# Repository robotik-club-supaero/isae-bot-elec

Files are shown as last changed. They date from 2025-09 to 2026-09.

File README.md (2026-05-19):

# Elec2025-26
elec 2025 2026 comme dans le titre en fait

# Pinout ESP32-Devkit

Ce guide fournit une référence exhaustive pour l'utilisation des broches du module **ESP32-DevKitC-32D**. Il récapitule les fonctions de chaque broche, classe les GPIO par niveau de sécurité, et liste les règles de conception essentielles pour éviter les comportements erratiques au démarrage (boot) ou le blocage du téléversement.
Lien vers un sheets qui est plutôt clair : https://docs.google.com/spreadsheets/d/1OCtBKPCofokwxsqIV4q3fY71EqnTtfXIetnAtifBfJc/edit?usp=sharing

---

## 🗺️ 1. Synthèse Globale du Pinout

> [!CAUTION]
> **DANGER CRITIQUE POUR LE MATÉRIEL :**
> **NE JAMAIS ENVOYER PLUS DE 3.3V A AUCUNE DES PINS GPIO de l'ESP32.** > Les broches ne sont pas tolérantes au 5V. Toute tension supérieure à 3.3V détruira instantanément la broche ou la puce entière. Utilisez un pont diviseur ou un Level Shifter pour les signaux autres.

### 🔌 Broches d'Alimentation et Contrôle Physique
Ces broches ne sont pas programmables. Elles gèrent l'infrastructure électrique et logique de la carte.

| Nom sur Schéma | Fonction Matérielle | Recommandations de Conception |
| :--- | :--- | :--- |
| **VIN** | Entrée d'alimentation principale (5V) | Liée au régulateur de tension interne. À utiliser pour alimenter la carte sans câble USB. |
| **3V3** | Sortie ou Entrée d'alimentation 3.3V | Sortie du régulateur interne ou entrée régulée. Ne jamais injecter plus de 3.3V sous peine de destruction. |
| **GND / GND1** | Masse de référence (0V) | Point commun pour tous les signaux et alimentations du système. |
| **EN** | Équivalent Hardware Reset | Maintenu à 3.3V en interne. Forcer à la masse (GND) éteint la puce. Une transition bas ➔ haut déclenche un Hard Reset. |

---

## 🚦 2. Classification des GPIO par Niveau de Sécurité

### 🟢 Liste Verte : 100% Sûres (Aucune restriction)
Ces broches sont entièrement bidirectionnelles, acceptent le mode `INPUT`, `OUTPUT`, les interruptions matérielles, ainsi que les résistances de tirage (*pull-up* / *pull-down*) internes. **À utiliser en priorité absolue.**

| Nom | N° GPIO | Fonctions Spécifiques / Alternatives |
| :--- | :--- | :--- |
| **IO13** | GPIO 13 | Entrée/Sortie standard |
| **IO14** | GPIO 14 | Sort du PWM au boot (Léger glitch possible à la mise sous tension) |
| **IO16** | GPIO 16 | Entrée/Sortie standard |
| **IO17** | GPIO 17 | Entrée/Sortie standard |
| **IO19** | GPIO 19 | Entrée/Sortie standard (Souvent utilisé pour SPI MISO) |
| **IO21** | GPIO 21 | Bus I2C Matériel : **SDA** (Par défaut) |
| **IO22** | GPIO 22 | Bus I2C Matériel : **SCL** (Par défaut) |
| **IO23** | GPIO 23 | Entrée/Sortie standard (Souvent utilisé pour SPI MOSI) |
| **IO25** | GPIO 25 | Intègre un DAC (Convertisseur Numérique-Analogique matériel) |
| **IO26** | GPIO 26 | Intègre un DAC (Convertisseur Numérique-Analogique matériel) |
| **IO27** | GPIO 27 | Entrée/Sortie standard |
| **IO32** | GPIO 32 | Entrée/Sortie standard |
| **IO33** | GPIO 33 | Entrée/Sortie standard |

### 🟡 Liste Orange : Entrées Uniquement (*Input Only*)
Ces broches sont uniquement capables de lire un signal électrique. La commande `pinMode(X, OUTPUT)` n'a aucun effet physique dessus.

| Nom | N° GPIO | Caractéristiques Critiques |
| :--- | :--- | :--- |
| **IO34** | GPIO 34 | **Pas de pull-up/pull-down interne**. État flottant sans résistance externe. |
| **IO35** | GPIO 35 | **Pas de pull-up/pull-down interne**. État flottant sans résistance externe. |
| **VP** | GPIO 36 | Sensor VP. **Pas de pull-up/pull-down interne**. Entrée idéal analogique. |
| **VN** | GPIO 39 | Sensor VN. **Pas de pull-up/pull-down interne**. Entrée idéal analogique. |

> 💡 **Le Super-Pouvoir de l'ADC1 :** Contrairement aux broches de l'ADC2, les entrées analogiques de l'ADC1 (**GPIO 34, 35, 36, 39**) restent parfaitement fonctionnelles et stables lorsque le module Wi-Fi de l'ESP32 est actif. Utilisez-les en priorité pour vos capteurs critiques (potentiomètres, mesures analogiques, joysticks).

### 🔴 Liste Rouge : Les Strapping Pins (Risque de blocage au boot)
Ces broches agissent comme des configurateurs matériels au moment précis de l'allumage. **Règle d'or : Ne jamais les câbler comme entrées reliées à des commutateurs ou capteurs actifs au démarrage.** Si nécessaire, utilisez-les préférentiellement en **Sortie (Output)** pour des composants non critiques.

| Nom | N° GPIO | Rôle au Démarrage / Comportement Attendu | Risque en cas d'erreur matérielle |
| :--- | :--- | :--- | :--- |
| **IO0** | GPIO 0 | **Boot Mode Select**. Haut = Exécution Normale. Bas = Mode Flashage/Téléchargement. | Bloque le téléversement ou empêche le code utilisateur de s'exécuter de manière autonome. |
| **IO2** | GPIO 2 | Doit être maintenu à l'état **BAS** (ou flottant) pour entrer en mode Flash. | Conjointement au GPIO 0, si forcé à l'état haut au boot, le flashage échoue. |
| **IO5** | GPIO 5 | Configure le timing du mode esclave SDIO. | Peut empêcher le processeur d'initialiser correctement certains bus. |
| **IO12** | GPIO 12 | **Tension Flash (VDD_SDIO)**. Haut = 1.8V. Bas = 3.3V (Nécessaire pour le module WROOM). | **Boot fails if high** : Si tiré vers le haut par un composant au démarrage, la mémoire flash manque de tension ➔ crash immédiat. |
| **IO15** | GPIO 15 | Contrôle l'émission des logs de debug de démarrage sur UART0. | Émet des micro-impulsions au boot (peut faire brièvement clignoter une LED ou commuter un transistor). |

### ❌ Liste Noire : Interdiction Absolue (Mémoire Interne SPI)
**Ne tentez jamais de les déclarer ou de les manipuler dans votre code.**
* **GPIO 1 (TX0) & GPIO 3 (RX0) :** Réservées au convertisseur USB-Série de la carte de développement. Les utiliser bloque le téléversement du code et casse la communication avec le Moniteur Série.

### Liste a éviter : Pins high au boot
Ces broches sont high (à 3.3V) pendant le boot & le setup. Connectez un composant (un moteur par exemple) dessus le fera démarrer à chaque upload du code. C'est chiant, on évite si c'est un composant qui reçoit du courant et qui produit une action. Un interrupteur, une led c'est ok par exemple
* [1 | 3 | 5 | 14 | 15] **GPIO 1 (TX0) & GPIO 3 (RX0) & GPIO 5 & GPIO 14 & GPIO 15 :** Sont high au boot & envoie des signaux pwm ou high

<p align="center">
  Pinout ESP32 DOIT DevKit V1
</p>

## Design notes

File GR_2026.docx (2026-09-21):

Gros Robot Architecture

Carte Alimentation
Carte Raspberry Hat
Carte Propulsion
Carte Action
Carte Constructeur

INTRODUCTION

Le gros robot (« GR ») est le robot principal du club. Il accompli les tâches les plus complexes et rapporte donc le plus de point.

Pour cela, il possède 5 cartes électroniques nécessaire à son bon fonctionnement :

- Carte Alimentation
- Carte Propulsion
- Carte Action
- Carte Raspberry Pi Hat
- Carte Constructeur

On va ici détailler les fonctions de chacune d’elle ainsi que leurs interconnexions.

DESCRIPTION GENERALE

Chaque carte possède sa propre fonction qui permet au robot de fonctionner :

- Carte Alimentation : Alimente les autres cartes du robot à partir de batteries mais aussi le lidar.
- Carte Propulsion : Gère les déplacements du robot (moteurs + odomètres) en connexion avec la carte constructeur.
- Carte Action : Gère tous les actionneurs et capteurs du robot. Refaite chaque année en fonction des règles.
- Carte Raspberry Pi Hat : Interface avec le Raspberry Pi. (Faire coucou à l’info pour plus de détails) .
- Carte Constructeur : Carte du constructeur des moteurs/odomètres. Seule carte professionnelle. Ne sera pas détaillée.

INTERCONNEXIONS

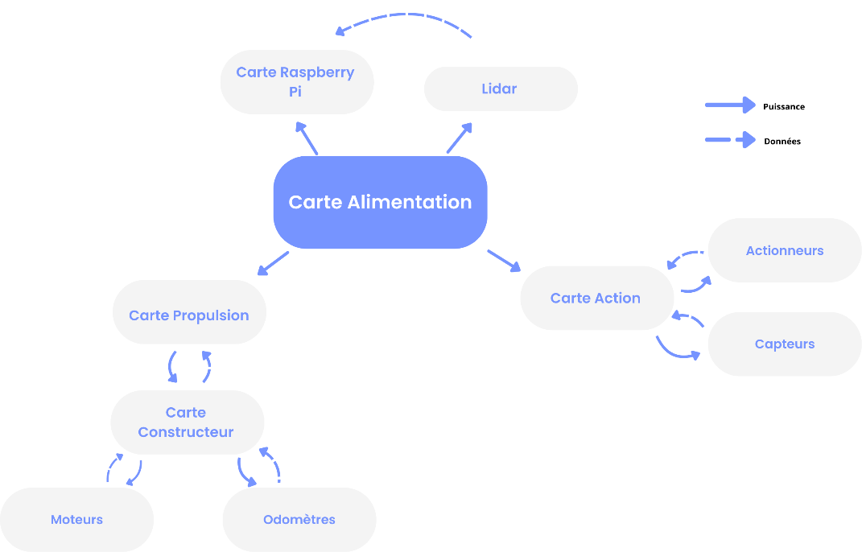
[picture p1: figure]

Les cartes ne sont pas indépendantes comme sur le schéma, elles communiquent entre elles avec ROS mais ça c’est le domaine de l’info :)

De plus, on divise tous les composants en deux catégories : La puissance et la logique.

- La puissance concerne les actionneurs comme les moteurs, les servos, les pompes, etc
- La logique concerne les capteurs, les microcontrôleurs, les odomètres, etc

CARTE ALIMENTATION

L’alimentation est le point central du robot, sans elle, rien ne marche. Elle permet :

- De générer les tensions d’alimentation nécessaire sur les autres cartes à partir de batteries de 24V.
- D’alimenter la carte Action en 5V, 12V, et 15V.
- D’alimenter la carte Propulsion en 24V.
- D’alimenter la carte Raspberry Pi en 5V.
- D’alimenter le Lidar en 5V ou 15V selon le modèle.
- Gérer le bouton d’arrêt d’urgence (BAU) et le l’interrupteur ON/OFF.

PS : Toutes les tensions de puissance seront notées _P et celles de logiques _L.

On peut la décomposer en 5 grandes parties :

- La batterie ainsi que le BAU et le ON/OFF contrôlés grâce à des relais. De plus, elle décompose la tension en deux : Une tension de puissance pour les actionneurs/capteurs (Vin_P) et une tension pour la logique (Vin_L).
- La conversion des tensions logiques. Les TSR1 génèrent du 5V à 1A maximum, et le TEN 30 génère du 5V à 6A maximum.
- Une 3ème gère la conversion des tensions de puissance. La TSR1 qui génère du 5V à 1A maximum, les TSR2 qui génèrent du 12V à 2A maximum.
- La redistribution vers les autres cartes à l’aide de connecteurs molex.
- Les leds témoins de chaque tension présente sur la carte.

La base a été faite en 2021 et modifiée cette année, en 2026, pour changer le convertisseur de tension du Raspberry car le nouveau model fonctionne en 5A.

SCHÉMA ÉLECTRIQUE

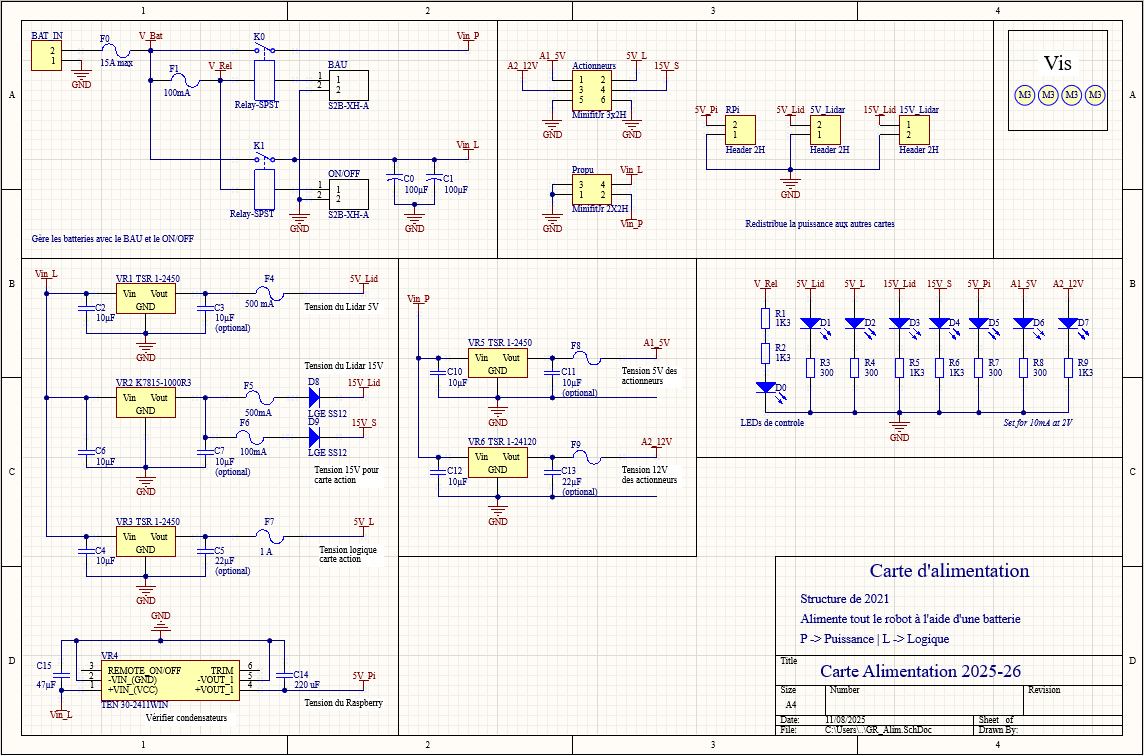
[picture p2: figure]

Et la carte de 2026:

- VR1: 5V-1A – TSR 1-2450
- VR2: 15V-1A – K7815-1000R3
- VR3: 5V-1A – TSR 1-2450
- VR4: 5V-6A – TEN 30-2411WIN
- VR5: 5V-1A – TSR 1-2450
- VR6: 12V-1A – TSR 1-24120
- VR6: 12V-2A – TSR 2-24120

Les convertisseurs réellement soudés sur la carte de 2021:

- VR2: K7815-1000R3 (15V–1A)
- VR3: TSR 1-2450 (5V-1A)
- VR4: TSR 1-2450 (5V–1A)
- VR5: THN 15-2411WIR (5V–3A)
- VR6: K7805-2000R3 (5V-2A)
- VR7: K7812-1000R3 (12V-1A)

COMPOSANTS

Les composants utilisés pour réaliser cette carte sont les suivants :

Composant | Valeur / Référence | Identificateur | Quantité
Relay SPST | / | K0, K1, K2 | 3
Minifit Jr | 2H | RPi | 1
| 2x2H | Propu | 1
| 3x2H | Actionneurs | 1
Traco | TSR 1-2450 | VR1, VR3, VR5 | 3
| K7815-1000R3 | VR2 | 1
| TSR 2-24120 | VR6 | 1
| THL 30-2411WI | VR4 | 1
Diode de retour | FERD20S100SB-TR | D0, D1 | 2
Connecteur JST | JST-XH-2 | BAT_IN, BAT_Pump | 2
| JST-XH-3 | Lidar | 1
Fusible | 15 A | F0, F2 | 2
Poly fuse | T0 / 100 mA | F1 | 1
| JF / 500 mA | F4 | 1
| BF / 1A | F5 | 1
Résistance | 0 Ω | F6, F7, F8 | 3
| 300 Ω | R3, R4, R6, R7 | 4
| 1 kΩ | R1, R2, R5, R8 | 4
Condensateur | 10 uF | C2, C3, C4, C8, C10, C11, C12 | 7
| 22 uF | C5, C9, C13 | 3
| 47 uF | C15 | 1
| 100 uF | C0, C1 | 2
| 220 uF | C14 | 1
LED | / | D2, D3, D4, D5, D6, D7, D8 | 7

DETAILS MECANIQUES

Dimensions :

- Longueur : 83 mm
- Largeur : 85 mm
- Fixations : 4 vis M3 (diamètre 3.2)

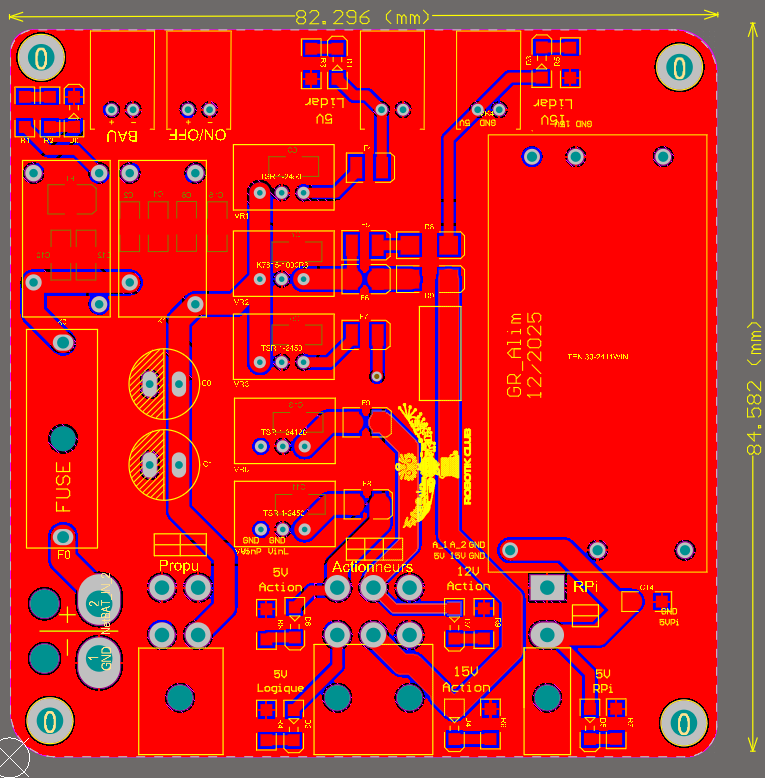
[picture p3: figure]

CARTE PROPULSION

La propulsion permet de gérer toute la direction du robot, à savoir les roues ainsi que les odomètres. Elle sert d’interface entre notre code et la carte constructeur :

- De fournir la tension d’alimentation de la carte constructeur, en 24V_P
- De convertir la tension 24V_L en 5V_L.
- De récupérer les données des deux odomètres.
- D’avoir des capteurs de fin de course pour se repositionner.

On peut la décomposer en 4 grandes parties :

- Les tensions de la carte d’alimentation qui convertissent le 24V_L en 5V_L à l’aide d’un TSR-1 2450 (max 1A) et distribuent le 24V_P à la carte constructeur.
- La teensy 4.0, le microcontrôleur de cette carte.
- Les connecteurs qui distribuent/récupèrent les données des moteurs, odomètres, et bumpers (capteurs de fin de courses).
- Les leds témoins de chaque tension présente sur la carte.

La base a été faite en 2023 et modifiée cette année, en 2026, pour passer à la teensy 4.0. Cela à impliqué l’ajout de level shifters pour les odomètres et on en a profité pour mettre 4 bumpers au lieu de 2.

SCHÉMA ÉLECTRIQUE

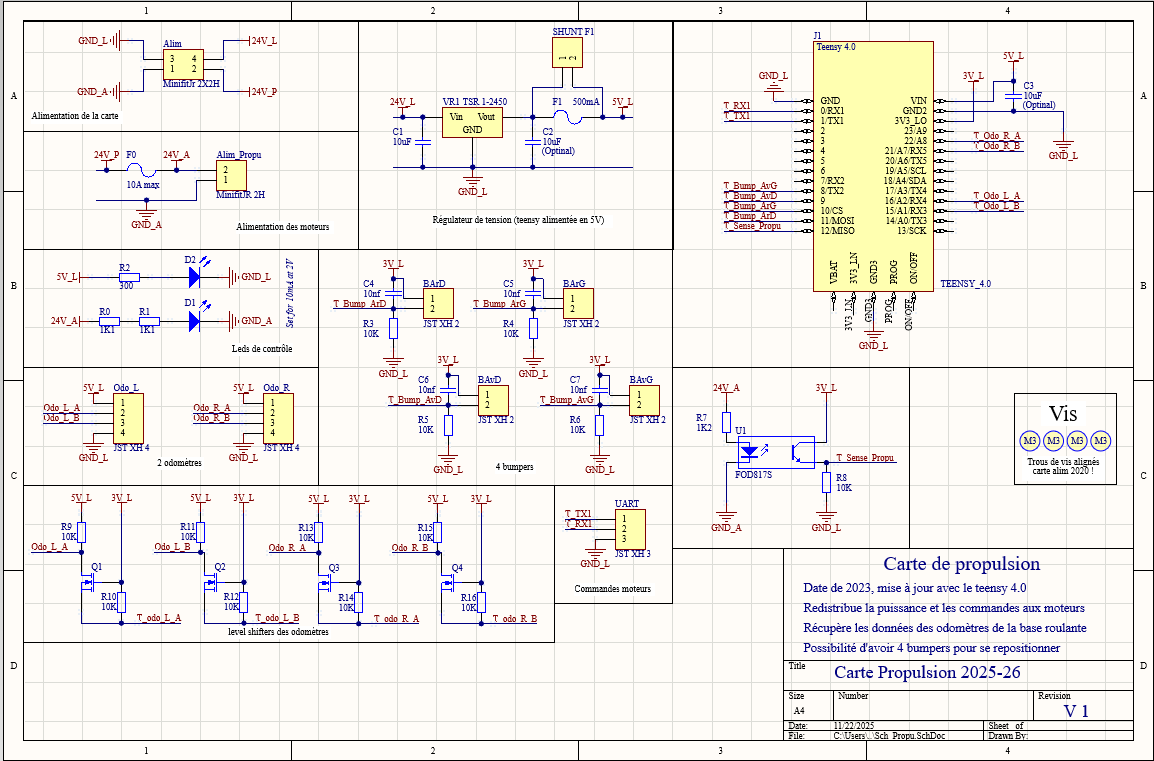
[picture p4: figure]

COMPOSANTS

Les composants pour réaliser cette carte sont les suivants :

Composant | Valeur / Référence | Identificateur | Quantité
Teensy 4.0 | / | J1 | 1
Minifit Jr | 2H | Alim_Propu | 1
| 2x2H | Alim | 1
Traco | TSR 1-2405 | VR1 | 1
Connecteur header 2 | / | SHUNT_F1 | 1
Connecteur JST | JST-XH-2 | BArD, BArG | 2
| JST-XH-3 | UART | 1
| JST-XH-4 | Odo_L, Odo_R | 2
Fusible | 500 mA | F1 | 1
| 10 A | F0 | 1
Condensateur | 10 nF | C4, C5 | 2
| 10 uF | C1, C2, C3 | 2
Résistance | 300 Ω | R2 | 1
| 1 kΩ | R0, R1 | 2
| 10 kΩ | R3…R16 | 13
Mosfet | N | Q1, Q2, Q3, Q4 | 4
LED | / | D1, D2 | 2

DÉTAILS MÉCANIQUES

Dimensions :

- Longueur : 87 mm
- Largeur : 45 mm
- Fixations : 4 vis M3 (diamètre 3.2)

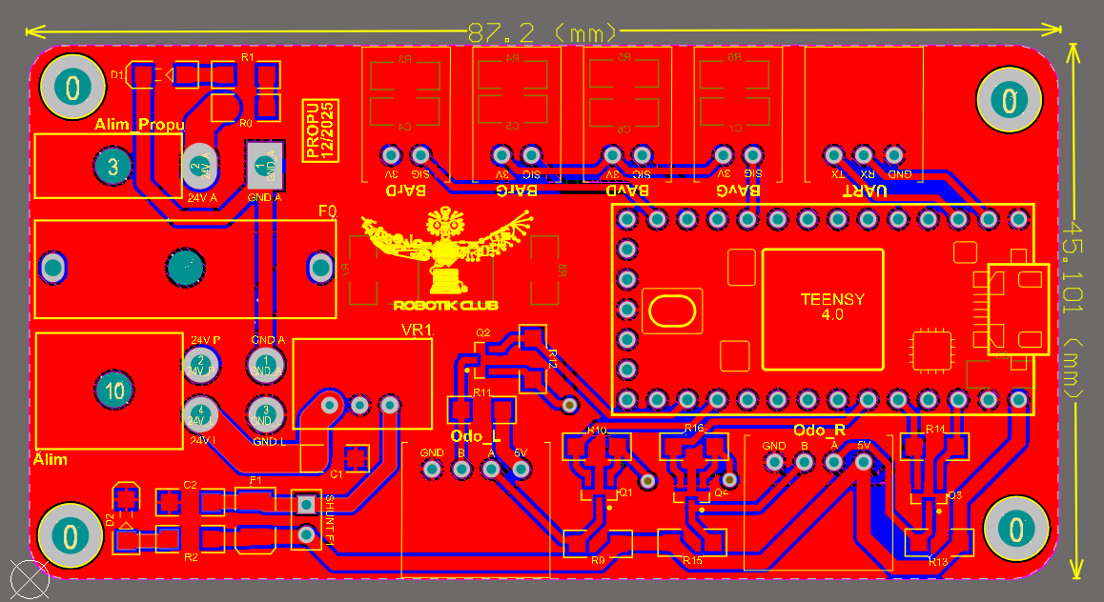
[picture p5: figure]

CARTE ACTION

La carte action est le centre du robot, c’est elle qui gère tous les actionneurs et les capteurs. C’est elle qu’on refait chaque année en fonction des nouvelles règles et qui demande le plus de travail. Elle dépend donc entièrement de ce qui est décidé chaque année.

Dans notre cas, elle possédait :

- Une teensy, le microcontrôleur de toute la carte
- 4 pompes ainsi que 4 photodiodes qui sont reliées à une carte de split pour gagner de la place
- 1 servomoteur reliée à la teensy par un optocoupleur
- 1 moteur DC contrôlé par son driver
- 2 bumpers
- 1 bouton pour déployer tous les actionneurs lors de l’homologation
- Des leds témoin de chaque tension

On utilise souvent des cartes de split quand on a plusieurs fois le même composant pour éviter d’avoir tous les connecteurs sur la carte qui peut être limité en taille.

SCHÉMA ÉLECTRIQUE

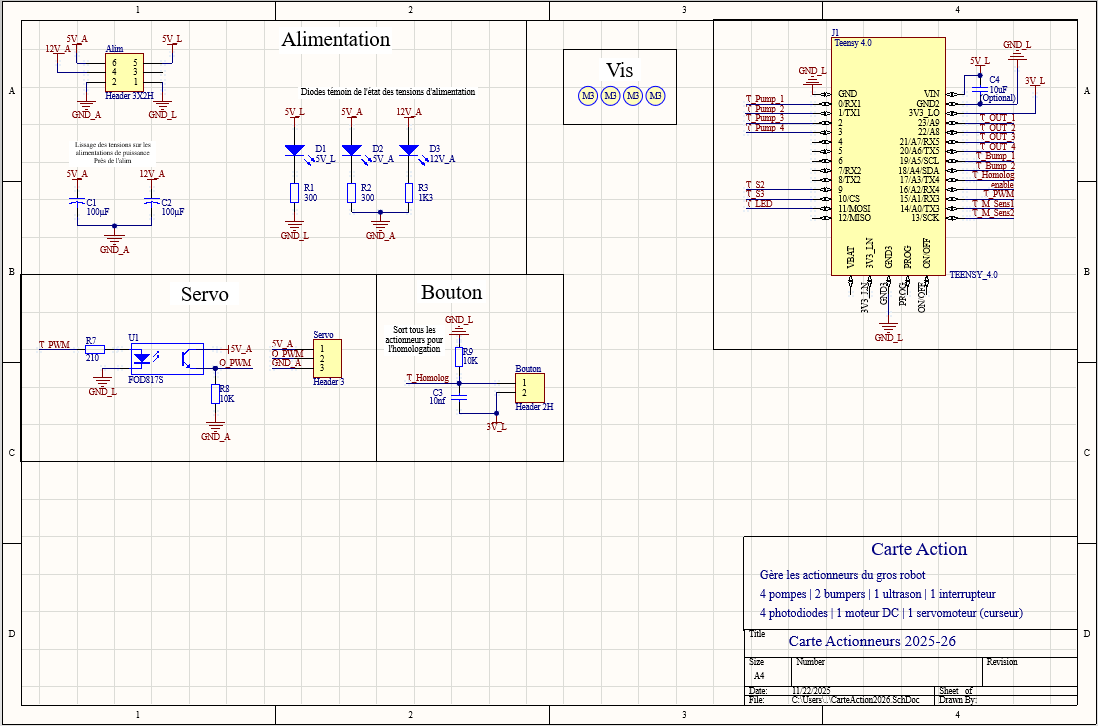
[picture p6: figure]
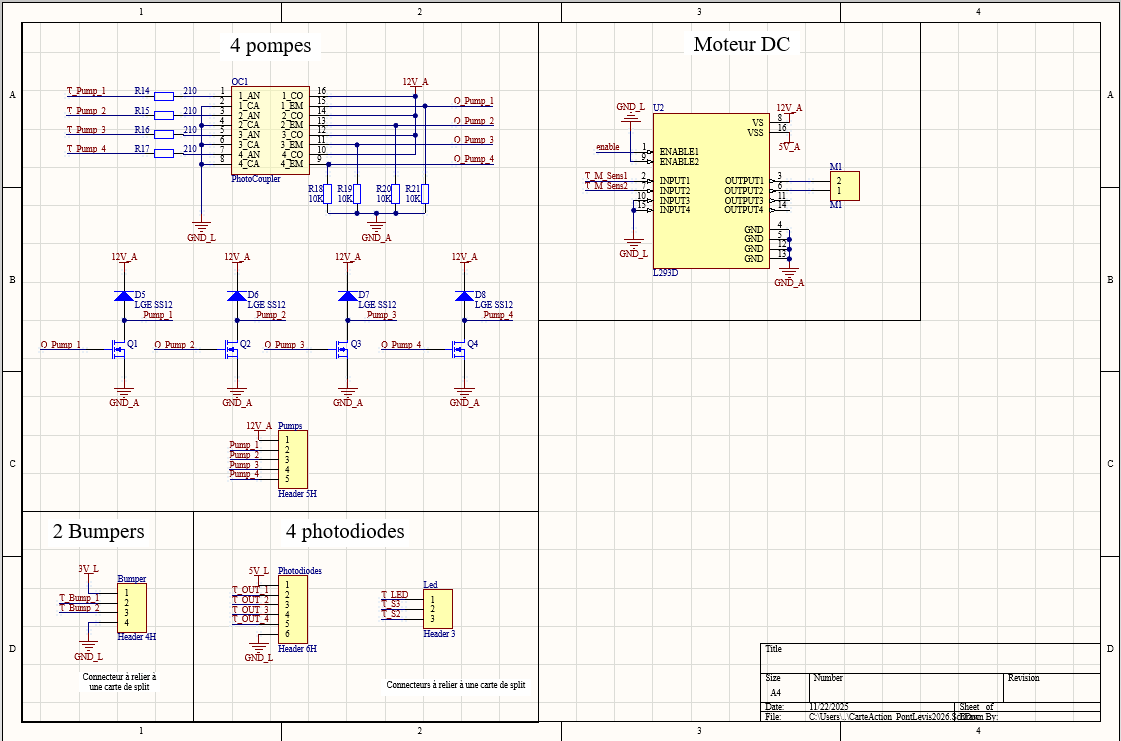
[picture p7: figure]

COMPOSANTS

Les composants utilisés pour réaliser cette carte sont les suivants :

Composant | Valeur / Référence | Identificateur | Quantité
Teensy 4.0 | / | J1 | 1
Driver moteur DC | DRV8871DDA | IC | 1
Optocoupleur | FOD817S | U1 | 1
Minifit Jr | 3x2H | Alim | 1
Connecteur JST | JST-XH-2 | Moteur DC, Bouton | 2
| JST-XH-3 | Servo | 1
| JST-XH-4 | Photodiode_S3, Photodiode_OUT, Bump | 3
| JST-XH-5 | Pumps | 1
| JST-XH-6 | Photodiode_S2 | 1
Mosfet-N | / | Q0, Q1, Q2, Q3, Q4 | 5
Diode | LGE SS12 | D5, D6, D7, D8 | 4
Résistance | 210 Ω | R7, R9, R11, R13, R15 | 5
| 300 Ω | R1, R2 | 2
| 1 kΩ | R3, R4 | 2
| 10 kΩ | R5, R8, R10, R12, R14, R16 | 6
| 33 kΩ | R6 | 1
Condensateur | 100 nF | C5 | 1
| 10 uF | C4 | 1
| 100 uF | C1, C2, C3 | 3
LED | / | D1, D2, D3, D4 | 4

DÉTAILS MÉCANIQUES

Dimensions :

- Longueur : 87 mm
- Largeur : 59 mm
- Fixations : 4 vis M3 (diamètre 3.2)

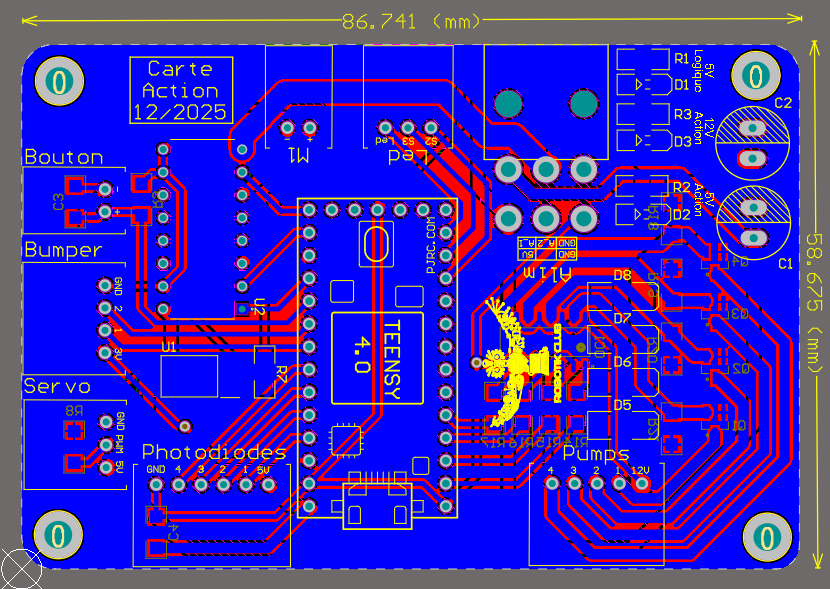
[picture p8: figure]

CARTE RASPBERRY PI HAT

Cette carte est une interface avec le Raspberry Pi afin d’y rajouter facilement des éléments, des connexions et rendre le tout plus modulable. Il s’agit de la carte de 2024 qu’on n’a pas modifié (Si ça marche, on garde !)

Dans notre cas, elle possédait :

- Des connecteurs pour le Raspberry Pi
- 4 connecteurs pour communiquer en I2C
- 1 connecteur UART
- 1 connecteur I2S
- 1 module Lora permettant la communication en 868 MHz (rajouté en 2024 mais rien d’autre n’a changé avec la carte de 2023 qu’on utilise peut-être je sais plus)
- Un circuit de protection entre l’alimentation et le Raspberry : ce circuit empêche les retours de tension et protège le Pi contre les surtensions.
- C’est également elle qui gère la tirette qui lance le début du match

SCHÉMA ÉLECTRIQUE

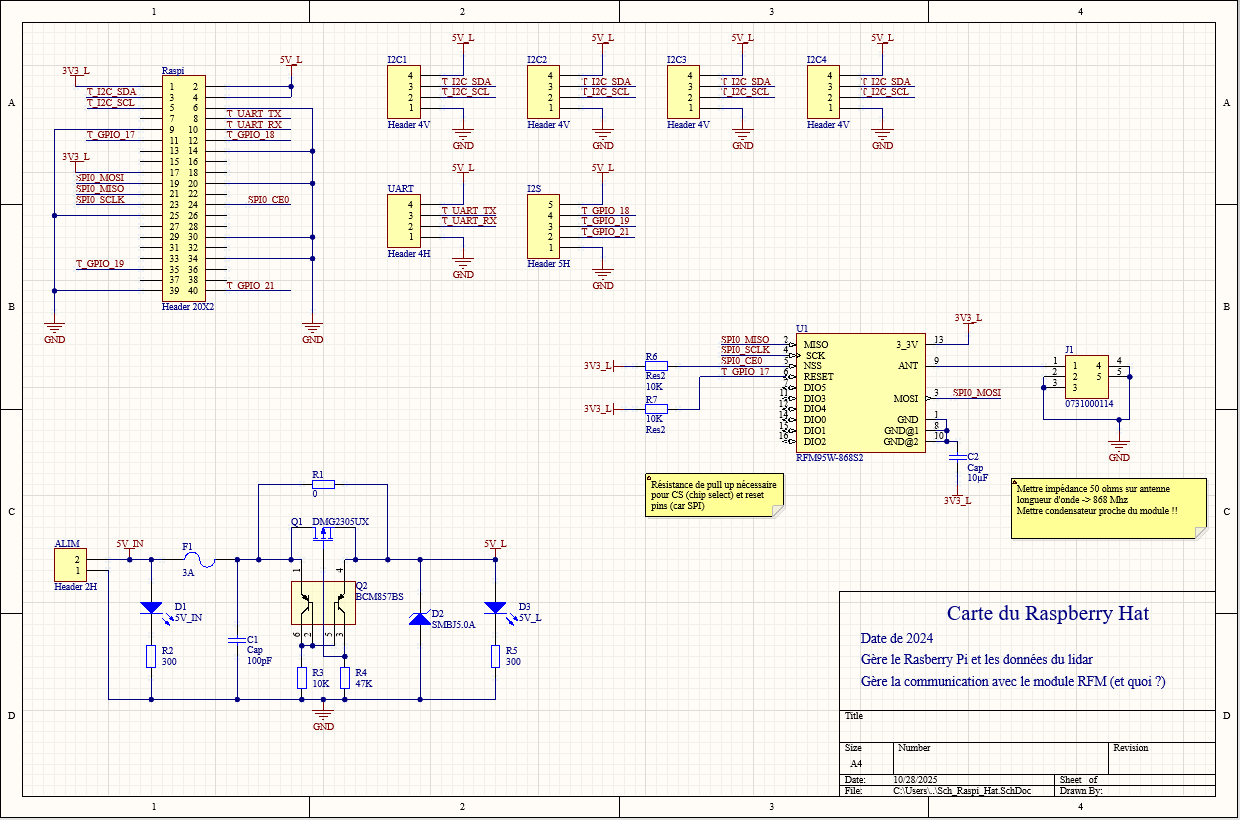
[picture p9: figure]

COMPOSANTS

Les composants pour réaliser cette carte sont les suivants :

Composant | Valeur / Référence | Identificateur | Quantité
Connecteur Header | 20x2 | Header 20X2 | 1
Module Lora | RFM95W-868S2 | U1 | 1
Molex Minifit Jr | 2x1H | Alim | 1
| B4B-XH-A | I2C1, I2C2, I2C3, I2C4, UART | 5
| B5B-XH-A | I2S | 1
Antenne | Une antenne simple, pas le composant de la carte | J1 | 1
Mosfet-P | DMG2305UX | Q1 | 1
Double transistor PNP | BCM857BS | Q2 | 1
Résistance | 0 Ω | R1 | 1
| 300 Ω | R2, R5 | 2
| 10 kΩ | R3, R6, R7 | 3
| 47 kΩ | R4 | 1
Condensateur | 100 pF | C1 | 1
| 10 uF | C2 | 1
Diode | / | D2 | 1
Led | / | D1, D3 | 2

DÉTAILS MÉCANIQUES

Dimensions :

- Longueur : 54 mm
- Largeur : 54 mm
- Fixations : Le Raspberry PI

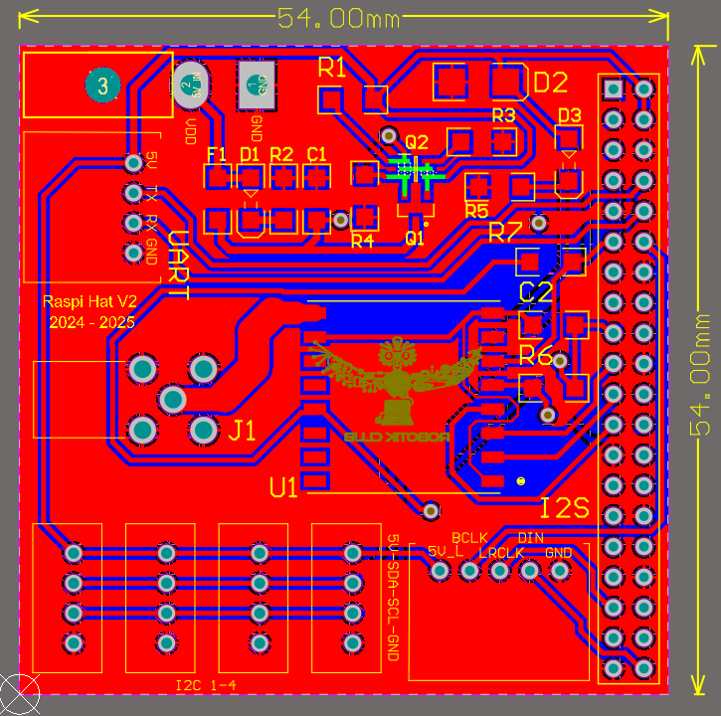
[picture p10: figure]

V 1Robotik 2026 – ELEC – Gros Robot1

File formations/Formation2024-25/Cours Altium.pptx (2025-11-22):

## La conception de circuits imprimés

avec le logiciel Altium

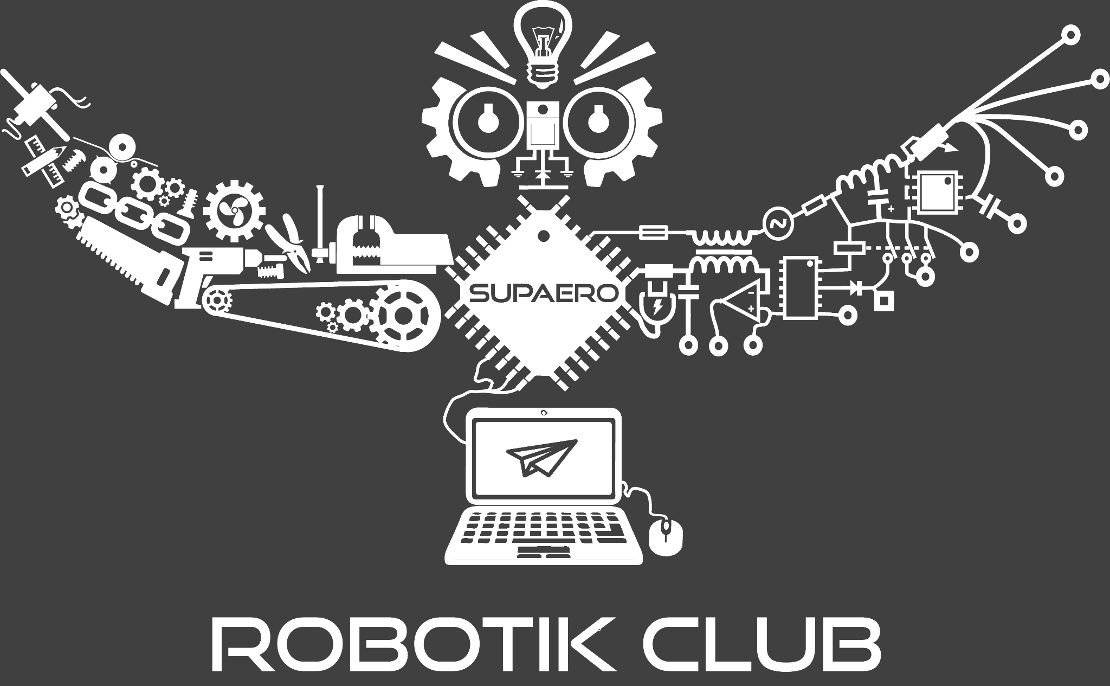
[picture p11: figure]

## Sommaire

- Qu’est-ce qu’un circuit imprimé (PCB) ?
- Pourquoi on utilise des circuits imprimés ?
- Les étapes de la conception d’un circuit imprimé:
  - Prérequis: Installer Altium Designer
  - Le schéma électrique
    - A quoi ça ressemble ?
    - Conception
    - Réalisation dans Altium
  - Le PCB
    - A quoi ça ressemble ?
    - Réalisation dans Altium
  - Commander son PCB

## Qu’est ce qu’un circuit imprimé (PCB) ?

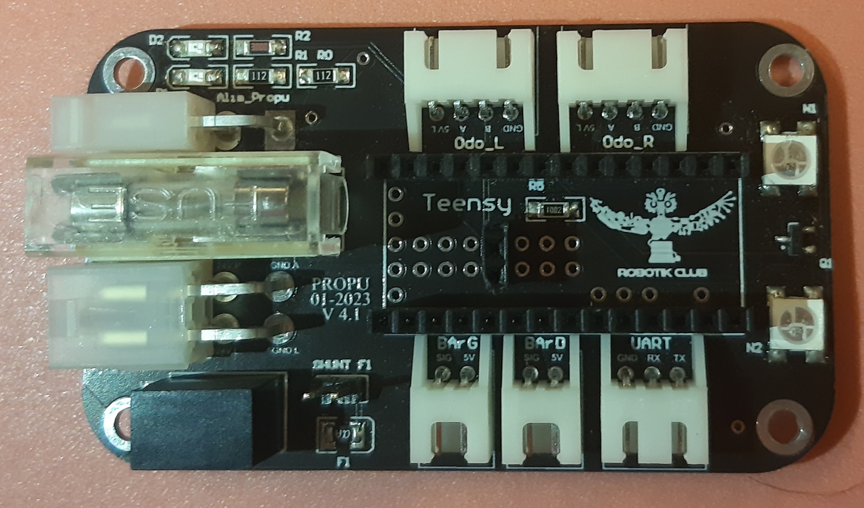
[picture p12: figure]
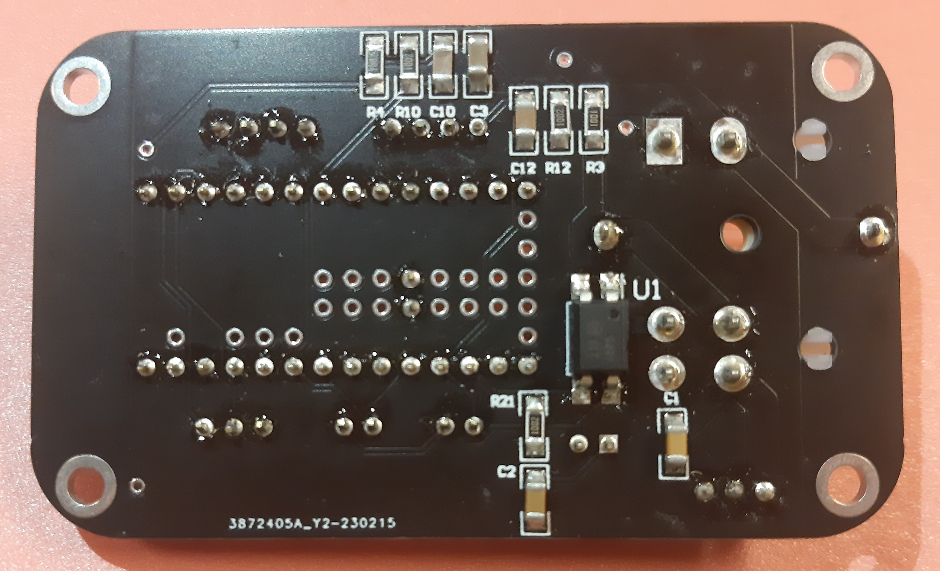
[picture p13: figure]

## Pourquoi on utilise des circuits imprimés ?

On doit distribuer correctement l’électricité apportée par notre source (la batterie du robot)
Pour cela, on doit:
- Alimenter les microcontrôleurs
- Permettre à ces microcontrôleurs de commander les actionneurs du robot en les alimentant de la bonne manière et avec le timing voulu
- Permettre à ces microcontrôleurs de récupérer les informations issues des capteurs du robot, qui doivent de plus être alimentés correctement

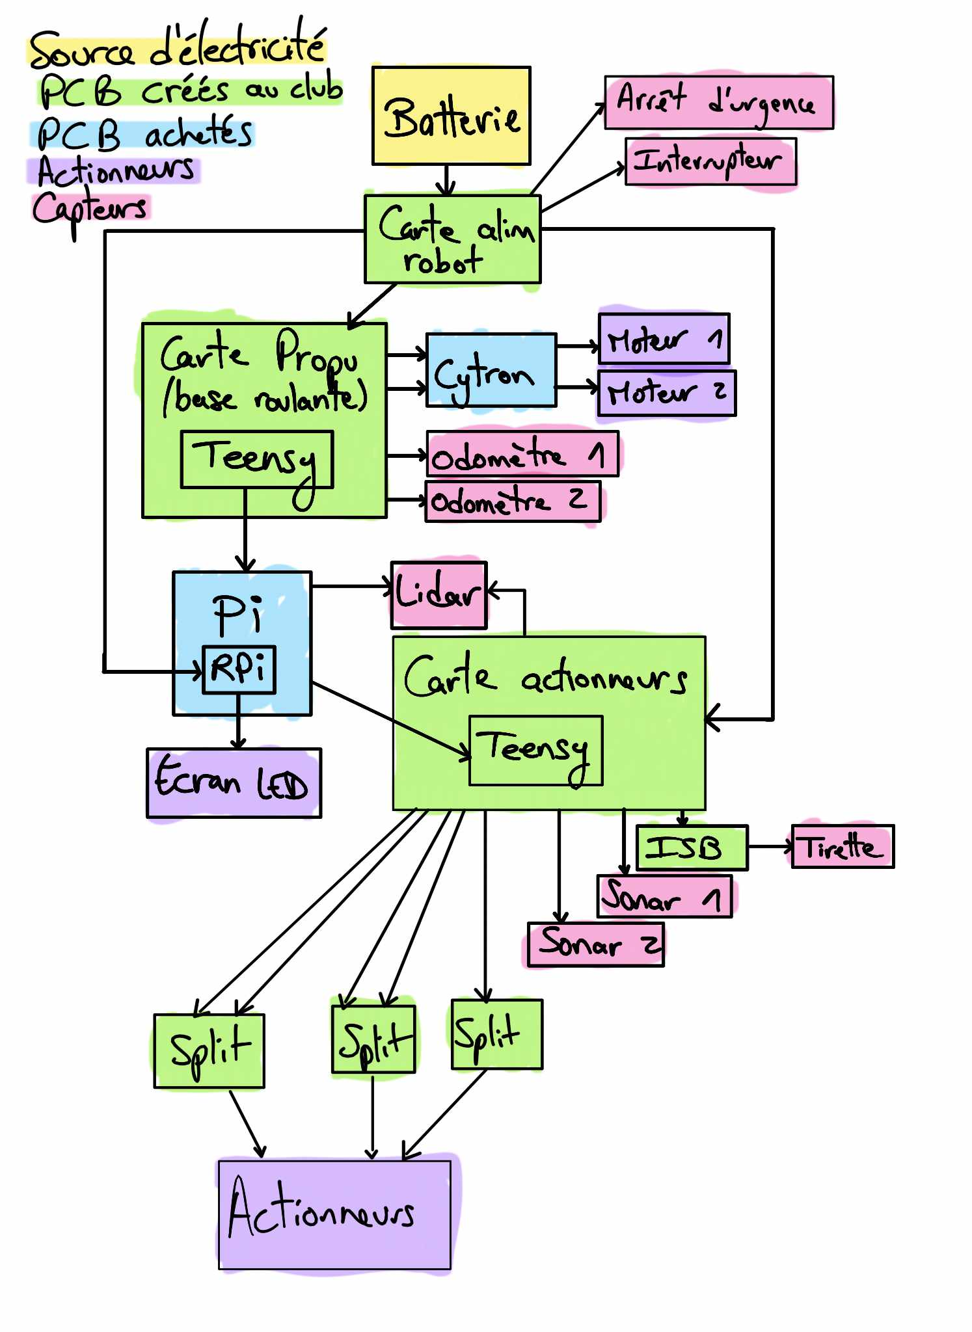
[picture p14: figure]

Architecture électrique type de nos robots

## Les étapes de la conception d’un circuit imprimé

## Prérequis : Installer Altium Designer

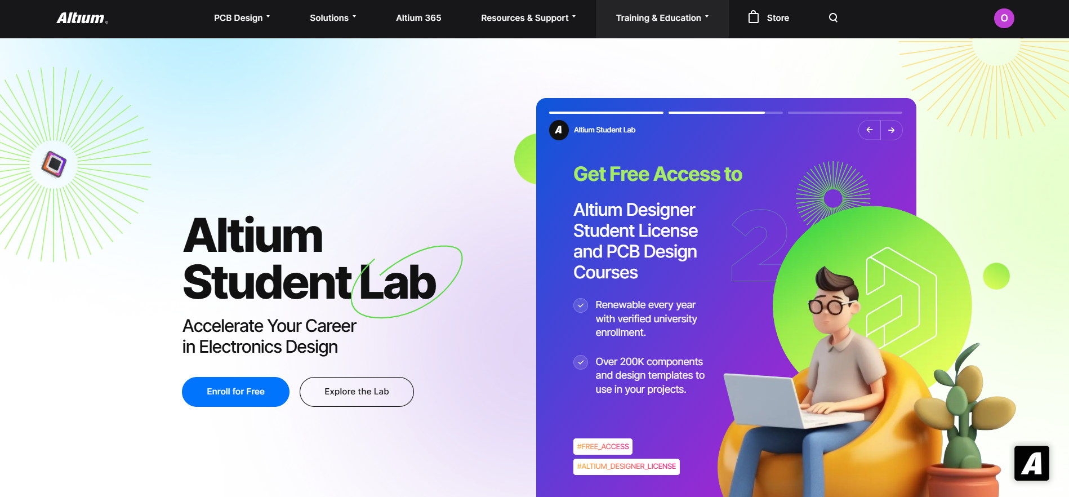
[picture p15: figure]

https://www.altium.com/education/students
Se référer au tutoriel d’installation d’Altium Designer 2024.
En cas de problème (le mail concernant la licence qui n’arrive pas par exemple), contacter le support pour les étudiants : students@altium.com (en anglais).

## Le schéma électrique - A quoi ça ressemble ?

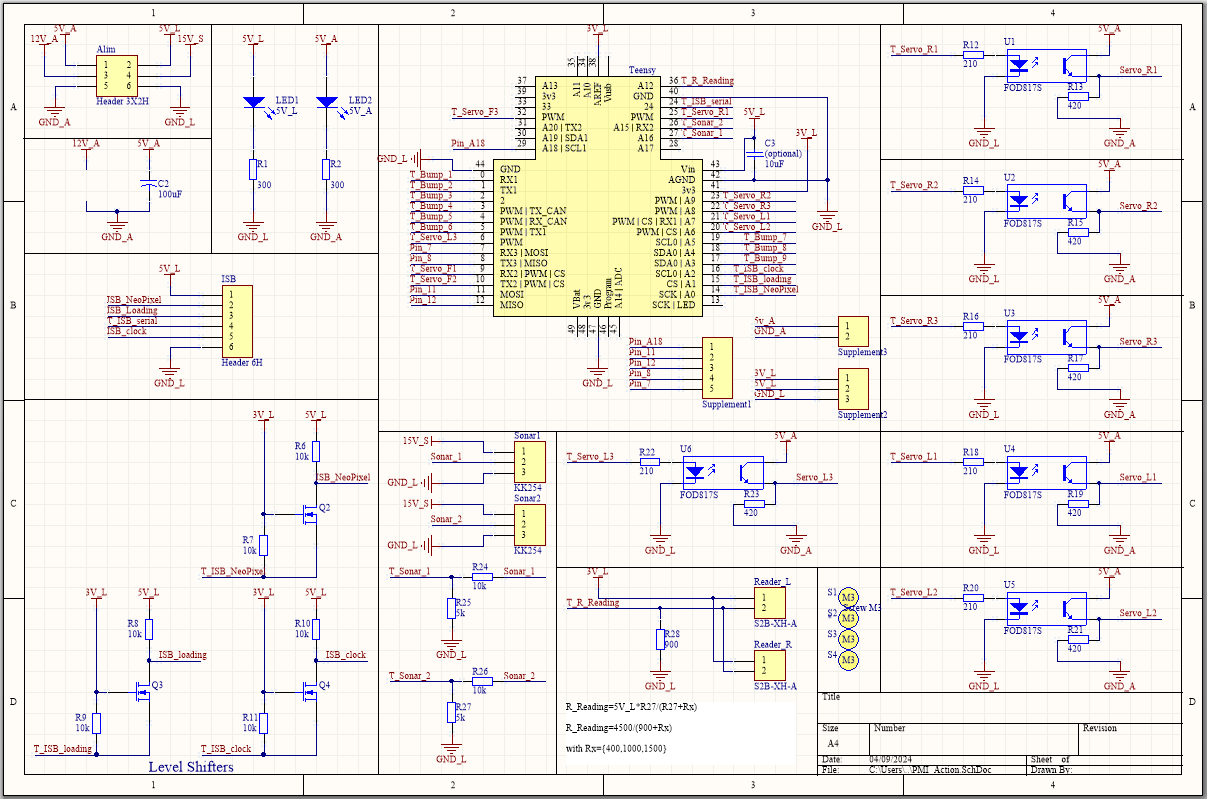
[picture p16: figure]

## Le schéma électrique - Conception

Avec quels composants je peux réaliser ces fonctions ? Comment relier tous les composants entre eux pour que ça marche ?

Qu’est ce que je veux faire ?

Comment je peux le faire ? Avec quelles fonctions ?

Exemple

J’ai besoin de générer un créneau entre 0V et un état haut supporté par ma LED. J’ai donc besoin d’un circuit générateur de créneau et d’un circuit pour réduire une tension, en plus de la LED

Je veux faire clignoter une LED avec une pile 9V

…

## Le schéma électrique - Réalisation dans Altium

- Pour chaque type de composant, on réalise les actions suivantes:
  - On ajoute le composant sur notre schéma
  - On vérifie que sa footprint correspond au composant réel que l’on veut utiliser
  - Si il y a plusieurs composants de ce type sur notre schéma, on le copie-colle
  - Si un composant possède une valeur (résistance ou capacité) on lui donne la valeur voulue

- Une fois tous les composants ajoutés, on les relie entre eux en traçant des fils et en utilisant des nets:
  - Plutôt que de relier absolument tout ensemble, on peut donner des noms aux fils. Deux fils qui ont le même nom seront considérés comme étant le même net et donc reliés entre eux.
  - Il existe des nets spéciaux pour matérialiser la/les masse(s) et la/les alimentation(s)

- Quelques bonnes pratiques additionnelles:
  - Donner des noms explicites et pratiques aux composants
  - Séparer les différentes fonctions dans le schéma par des traits pour faire des blocs
  - Ajouter des commentaires pour décrire ces fonctions
  - S’inspirer du travail des années précédentes

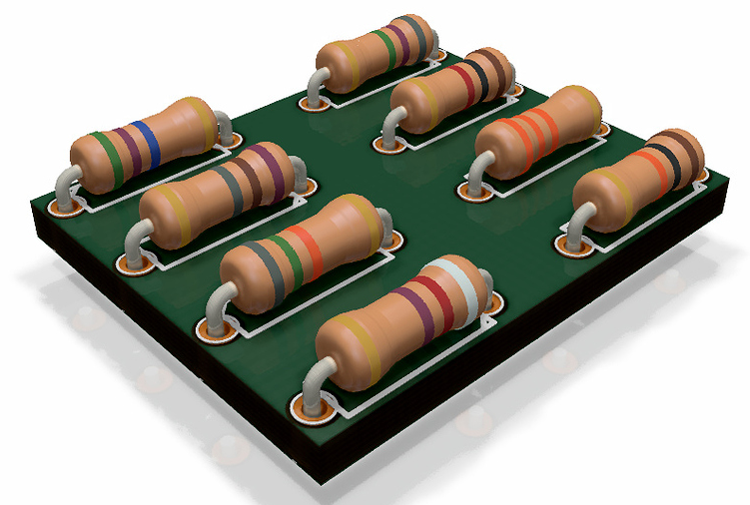
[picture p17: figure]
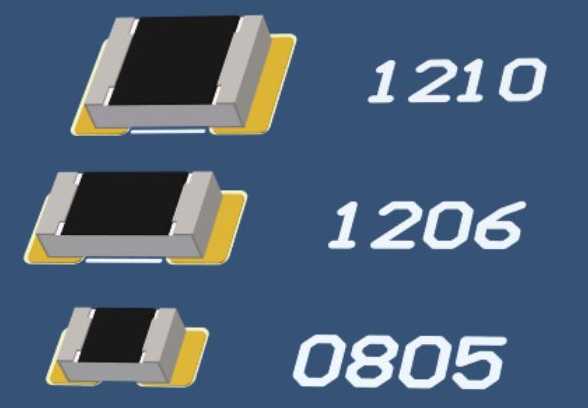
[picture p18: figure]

## Le PCB - A quoi ça ressemble ?

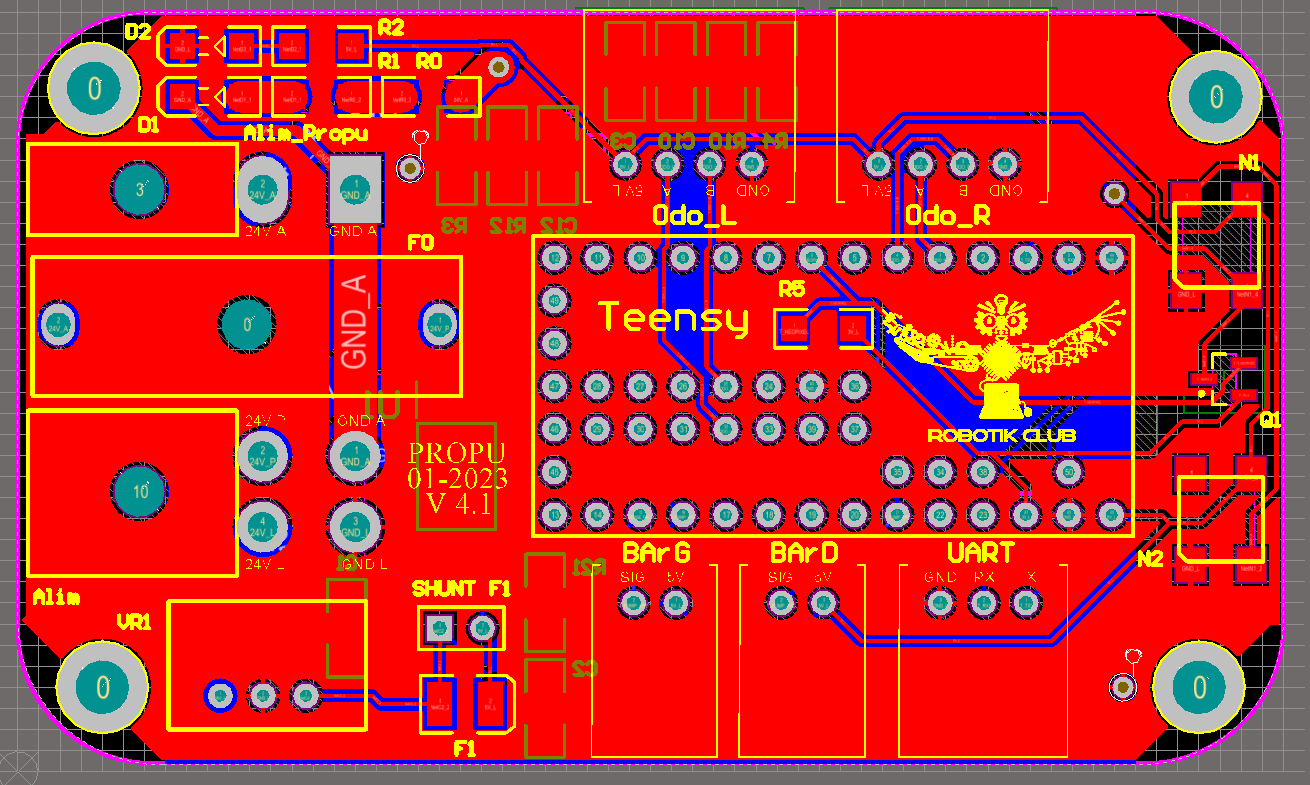
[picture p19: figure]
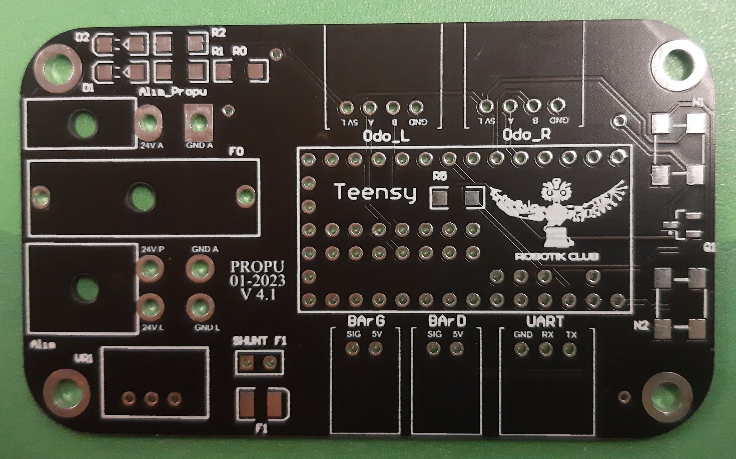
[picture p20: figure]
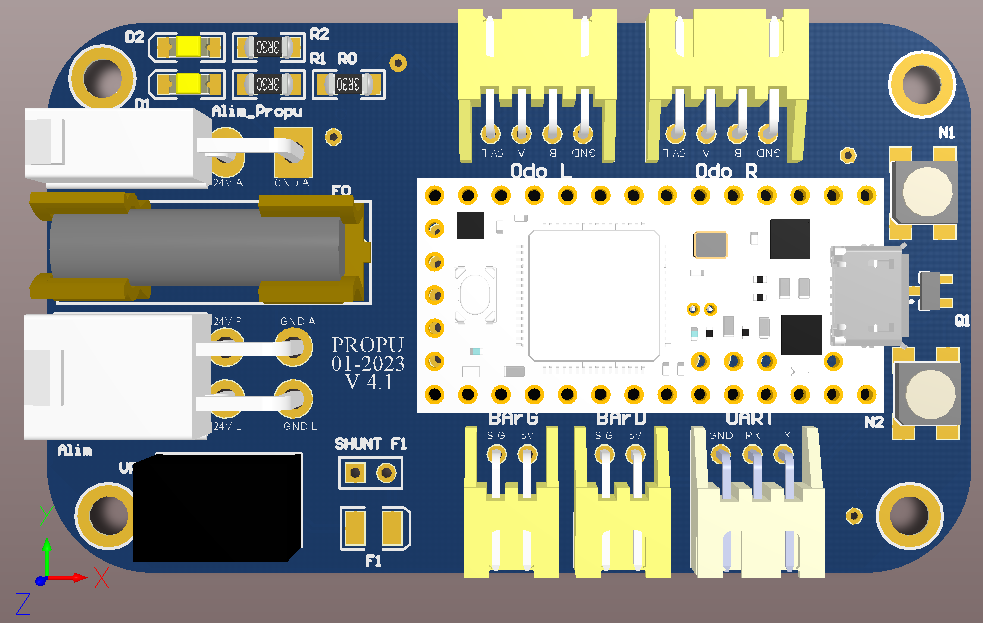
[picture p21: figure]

## Le PCB - Réalisation dans Altium (1)

Les grandes étapes de la réalisation d’un PCB:
- Importation de tous les composants du schéma électrique réalisé précédemment
- Détermination de la taille/forme du PCB
- Placement des composants sur le PCB
- Routage des composants (on les relie entre eux)
- Génération d’un plan de masse
- Ajout des trous de vis
- Ajout de texte : nom, version, année de la carte - légende pour les connecteurs - logo
- Vérification du PCB

## Le PCB - Réalisation dans Altium (2)

Règles et conseil du placement routage (un puzzle):
- On commence par placer les composants avec le plus de pins plutôt au centre
- On peut utiliser les deux faces du PCB
- Il faut placer les composants astucieusement pour que les pistes ne se croisent pas (ou le moins possible → on peut tricher en faisant passer une piste sur la face opposée pour le croisement puis en la faisant revenir, mais c’est à utiliser avec modération)
- Il faut choisir la largeur des pistes en fonction du courant qu’elles seront amenées à faire transiter (https://www.digikey.fr/en/resources/conversion-calculators/conversion-calculator-pcb-trace-width)
- On évite de faire des angles droits ou aigus avec les pistes, ou d’en enchaîner inutilement
- Avoir une souris (sinon c’est de la torture)

## Commander son PCB

Entreprise qui réalise des PCB (pour pas cher) : https://jlcpcb.com/
Pour générer les fichiers qui servent à commander sur ce site: https://support.jlcpcb.com/article/42-how-to-export-altium-pcb-to-gerber-files
Bon à savoir:
- Les PCB se commandent par 5
- La livraison “normale” prend 3 semaines, il faut en tenir compte dans les délais des projets
- La livraison “rapide” permet d’avoir un PCB qui arrive plus vite (~ 1 semaine) mais ça coûte bien plus cher

## Annexes

## Lien vers une vidéo qui détaille l’utilisation d’Altium pour concevoir un PCB de zéro: https://www.youtube.com/watch?v=6N2A6LtBWh0

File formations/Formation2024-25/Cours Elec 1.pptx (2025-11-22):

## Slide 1

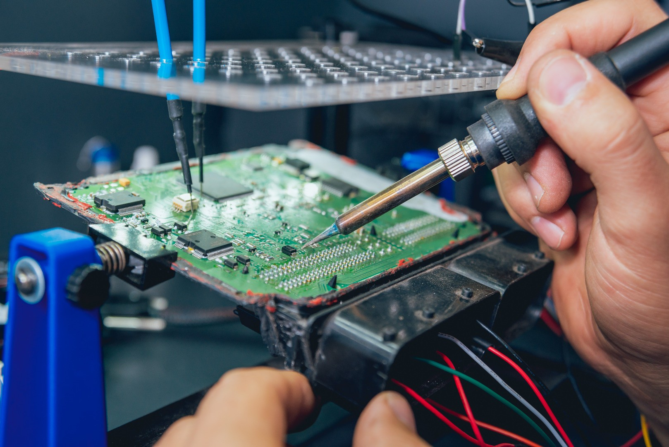
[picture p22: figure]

Formation électronique

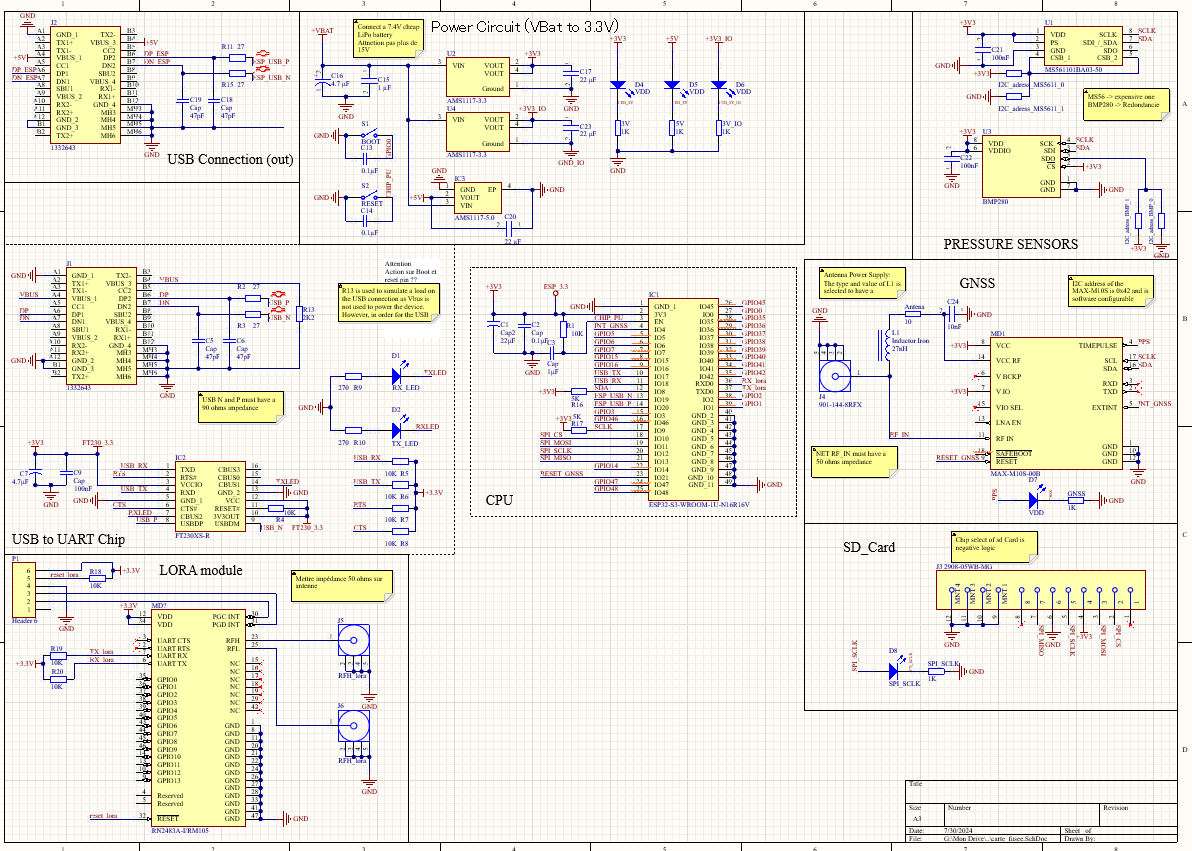
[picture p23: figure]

Cette première slide provient d’un vieux A (Benjamin) , je ne suis pas responsable de cette police XD

## Sommaire

- Les actionneurs et capteurs des clubs techniques
- Transistors (npn, pnp, mosfet …)
- Résistances de pull up / pull down
- Level shifters et optocoupleurs
- Différents protocoles série (UART, I2C, SPI, USB)
- Adaptation d’impédances

## Les actionneurs et capteurs des clubs techniques

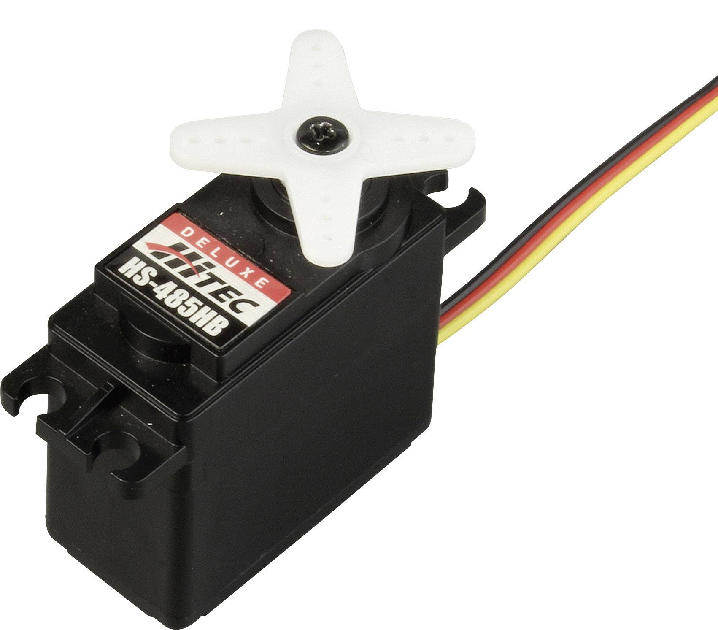
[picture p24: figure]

Servo moteurs


Micro-contrôleur


Moteurs CC et ponts en H

Micro Processeur


IMU

## Mosfet

Principe: interrupteur actionné avec un petit courant sur la base
Permet de faire pleins de choses (level shifter, control moteur …)


- S’active en fonction de la tension à la gate
- utile pour électronique de puissance
- condensateur entre Gate et source
- mosfet passant : VGS>VT (entre 0.4 et 0.7V)


## Transistors BJT (beaucoup moins utilisé) Bipolar junction transistor


+

+

β= Hfe= Ic/IB


Attention: VCE doit être suffisamment grand pour ne pas saturer
De même pour UBE (en général entre 0.6V et 0.7V)

B : Base
C : Collecteur
E : Emetteur

## Résistances de pull up / pull down


Permet d’éviter d’avoir une connection flottante dans le circuit → état random lu par le contrôleur
Pour savoir si il faut une pull up ou down regardé la datasheet !

## level shifters


Attention : ne pas avoir des fréquences trop élevées


Permet de transformer un signal de commande d’une tension faible à une tension plus élevé
Ex: Relais, servo moteur …

3.3V

5V

Pour réduire la tension utiliser un simple diviseur de tension avec 2 résistances

## optocoupleurs


Permet en plus d’isoler les masses
Sert à ne pas propager le bruit d’un circuit à l’autre (dans le gnd de puissance notamment)

Utilisation :
- Moteur cc
- isolation électronique de puissance/ électronique de commande
- …

Attention à la chute de tension des leds du module (1-2V car IR)

## Différents protocoles séries (UART, I2C, SPI, USB)


Objectifs:
→ Transférer un bits à la fois (plus lent mais moins de fils)


→ Signal asynchrone contient des bits de synchronisation avant chaques paquets
→ signal synchrone: clock fournit par le maître

## UART


Attention : connecter TXD de l’un au RXD de l’autre !!
RXD → receive, TXD → transfer

→ Protocol le plus simple
→ Uniquement 2 périphériques
→lent (jusqu’à 100kb/s)
→ utilisé pour programmer des contrôleurs
→ d’autre fils (RTS, CTS, …) plus utilisés de nos jours

## I2C


→ Chaques esclaves a une adresse physique de 7 bits modifiables
→ Plusieurs périphériques
→ rapide (400 kbits/s)
→ Protocole plus complexe
→ sur courte distance
→ adresse pas forcément modifiable ou juste le dernier bit

Attention : Mettre des résistances de pull up entre 4 et 5 kΩ sur sda et scl
SDA: serial data line, SCL: serial clock line

## SPI


→ Protocol pouvant nécessiter bcp de GPIO
→ Plusieurs périphériques
→Très rapide (centaines de Mhz)
→ Protocole peu contraignant
→ peut nécessiter un réglage d’impédance

Attention : Si le maître parle à l’esclave 2, l’esclave 1 doit mettre MISO en état flottant → pas de pull up/down (cependant mettre pull up sur ss)
MOSI : master in slave out, MISO : Master in slave out, ss : slave select, sclk : signal clock

## Adaptation d’impédance

Peut être nécessaire si distance grand et vitesse de transmission élevée (Ex: protocol USB)


33 Ω

33 Ω

33 Ω

En général impédance de 50 ohms

Pourquoi ?
- permet d’éviter d’avoir des signaux réfléchis ce qui crée des signaux stationnaires (aller voir vos cours de prépa)


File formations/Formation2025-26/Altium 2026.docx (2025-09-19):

Club Robotik : Formation Altium

I. Configuration Altium
  a. C’est quoi ?
  b. Installation
  c. Github & Librairies
II. Création des cartes
  a. Projet
  b. Schéma
  c. PCB
III. Commande du PCB
IV. Annexes
  a. Librairies & Composants
  b. Tips Altium

I - a. Altium, c’est quoi

Altium est un logiciel complexe permettant de créer ses propres cartes électroniques : des schémas, des pcbs, le routage, la visualisation 3D, etc.

En gros, Altium c’est un logiciel complexe qui permet à n’importe qui de créer des circuits imprimés.


Ca c’est l’architecture électrique type de nos robots, c’est toujours la première étape avant de créer des cartes. On y met tous les composants qui se trouveront sur notre robot regroupé en plusieurs groupes qui donneront chacun une carte différente : L’alimentation, la propulsion, et enfin les actionneurs.


Après l’architecture, on passe au schéma électrique qui détaille les composants (il existe des dizaines de référence pour faire la même chose, lequel on prend ?) et toutes les connexions entre les composants.


Ça, ce sont les PCB. Après le schéma, on choisit où on les placer sur la carte et par où faire passer les fils.

Vue 2D Vue 3D et finale


Ensuite on commande le PCB au fabriquant et on reçoit ça : Une carte avec toutes les connexions de faites mais aucun composant


La dernière étape est donc de souder tous les composants sur la carte pour avoir la version finale.

I - b. Installation d’Altium

Se référer au fichier : Tutoriel installation Altium Designer 2024.pdf - fais par un super 3A Thomas Roberge ;)

I - c. Github et Libraires

Le pôle électronique à un github (aller voir la formation github du pôle info pour plus de détails) que vous retrouverez ici : https://github.com/Jean-Michel-Robot/Elec2024-25. Cloner tout sur votre machine.

Vous devez ainsi avoir un dossier Elec2025-26, un libs, un old_repos.

Elec2025-26 contiendra tous les fichiers de l’année que vous allez créer. Le dossier libs contient toutes les librairies avec tous les composants utilisés par le club. Et old_repos contient toutes les cartes des années précédentes (elles vont être très utiles).

Installation des librairies du club (fichier .PcbLib & .SchLib & .IntLib)

L’étape suivante n’est à faire qu’une seule fois ! (Normalement)

Maintenant, on doit installer ces librairies sur Altium avant de commencer à travailler sur un projet. Il semblerait que les librairies soient liées à Altium et non un workspace en particulier donc il n’y a pas besoin de refaire la manipulation lorsque l’on change de workspace ou de projet

● Ouvrir l’onglet librairies en cliquant sur View > Panels > Components > > librairies preferences

● Cliquer sur la case Add Librairies en bas à droite de l’onglet librairies

● Sélectionner avec Ctrl+A tout le contenu du dossier libs du Github puis cliquer sur ouvrir et quitter la fenêtre

Créer un workspace (Design Project Group (fichier .DsnWrk))

L’étape suivante n’est pas à faire, les 2A l’auront fait pour vous mais ça peut être utile

● File > New > Design Project Group

● File > Save Project Group As > Enregistrer le workspace que l’on vient de créer dans un nouveau dossier à l’endroit où l’on souhaite travailler, avec un nom explicite.

C’est dans ce workspace que seront enregistrées toutes les cartes faites sur une année, c’est un fichier sommaire en gros qui contient tout – c’est lui qu’on ouvre quand on veut rouvrir un vieux projet.

II. Schéma et PCB

On va maintenant créer des projets dans notre workspace (le fichier .DsnWrk qui est un fichier général contenant toutes les cartes de notre robot crée juste avant) et dans chacun de ces projets, on mettra une carte (un fichier .PcbDoc – plus bas à droite) ainsi que son schéma électrique (un ou plusieurs fichiers .SchDoc –plus bas à gauche)

Voici un exemple d’architecture :


II - a. Projet

Créer un projet (fichier .PrjPcb)

L’étape suivante est à faire à chaque nouvelle carte !

● Vérifier que l’on se trouve bien dans le workspace dans lequel on souhaite travailler et changer si ce n’est pas le cas. Pour vérifier, on regarde ce qu’il y a écrit dans l’onglet Projects dans la case à gauche de Workspace. Pour changer, on va dans File > Open et on choisir le bon workspace. Si l’onglet Projects n’est pas ouvert, on peut le récupérer en cliquant sur View > Panels > Projects

● File > New > Project… ouvre une boite de dialogue dans laquelle on choisit le nom de notre projet (par exemple carte_action.PrjPcb)

● File > Save Project As > Enregistrer le projet que l’on vient de créer dans un nouveau dossier dans l’emplacement proposé, avec un nom explicite

● File > Save All permet de mettre a jour le workspace (Le petit anneau rouge à droite du nom dans l’onglet projet signifie que le workspace n’a pas été enregistré depuis la dernière modification)

II - b. Schéma

Créer un schéma électrique (fichier .SchDoc)

L’étape suivante est à faire à chaque nouvelle carte !

● Vérifier que l’on se trouve bien dans les workspace et projet dans lesquels on souhaite travailler, et changer si ce n’est pas le cas. Pour vérifier, on regarde ce qu’il y a écrit dans l’onglet Projects dans les cases à gauche de Workspace et Project. Pour changer de projet, on peut simplement cliquer sur son nom dans la liste du milieu de l’onglet Projects. Si l’onglet Projects n’est pas ouvert, on peut le récupérer en cliquant sur View > Workspace Panels > System > Projects

● Clic droit dans le milieu de l’onglet Projects > Add New To Project > Schematic

● Clic droit sur le nom du schéma dans l’onglet Projects > Save As > Enregistrer le schéma que l’on vient de créer à l’endroit proposé, avec un nom explicite.

● File > Save All

Réaliser le schéma électrique d’une carte

● Pour ouvrir un schéma électrique créé précédemment, double cliquer depuis l’onglet Projects sur son nom.


● Ajouter les composants voulus un à un. Pour ajouter un composant, il faut ouvrir l’onglet Components (Cliquer sur View > Panels > Components s’il n’est pas rabattu sur la droite, ou sur son nom s’il l’est). On sélectionne la librairie voulue dans le menu déroulant en haut (se référer à plus bas, section IV - a, pour savoir laquelle choisir, puis on peut taper ou non toute ou partie du nom du composant dans la case qui suit. Finalement, on choisit le composant voulu dans la liste déroulante et on le fait glisser vers notre schéma. (Tips : Si l’on a besoin de plusieurs composants identiques, il est préférable de n’en ajouter qu’un à ce stade et de copier ce dernier après l’étape suivante).

● Pour chaque composant ajouté, il faut vérifier que sa footprint est celle que l’on souhaite (voir plus bas, section IV - a, pour savoir ce que le club utilise). Pour cela, on double clique sur le composant et on se reporte à l’encadré Parameters en bas puis on appuie sur show (image à droite). Enfin, on voie la footprint (on clique s’ils nous disent de « click to display preview »). Si ce n’est pas la bonne ou si rien n’apparait, on doit la changer.

● Pour changer de footprint, on peut accéder à la liste déroulante avec le bouton Add… > Footprint et ensuite on cherche dans les librairies de footprint celle qui nous convient en cliquant sur la case Browse… en haut. (Tips : Attention la fonction de recherche est stupide, elle ne cherche pas ce qui se trouverait au milieu des noms, mais seulement au début.).

Cas très rare mais utile à avoir :

Pour certains composants on pourrait avoir besoin de modifier les pins, il faut alors cliquer sur Pins… (cas très précis - ne surtout pas toucher sinon).

Une fois la footprint ajoutée on peut appuyer sur Ok puis on vérifie bien que la bonne footprint est sélectionnée et on rappuie sur Ok. A ce stade, on peut maintenant copier nos composants (avec ctrl+c / ctrl+v ou un clic droit).

● Pour les composants tels que les résistances et capacités, il est conseillé d’indiquer dans le schéma la valeur que l’on souhaite leur donner (en ohm ou farads). (Tips : Bien que cela ne soit pas utile d’un point de vue purement création de PCB, puisque la valeur de changera pas leur taille ou autre, il est important de le faire car le fonctionnement de la carte va en dépendre). Pour modifier cette valeur (qui normalement est visible à côté du composant sur le schéma), on double clique dessus et on se reporte à la ligne Value de l’encadré Parameters. Si la valeur n’est pas affichée, il faut cocher la case Visible juste à gauche de Value. (Tips : On peut également double cliquer sur la valeur et modifier directement sur le schéma.)

● Une fois que tous les composants ont été ajoutés sur le schéma, il faut les relier correctement entre eux. Une chose très importante à garder en tête pour cela est l’existence des nets. En fait, il ne faut surtout pas relier tous les composants entre eux avec des fils, mais plutôt donner des noms à certains d’entre eux, pour éclater le schéma en blocs, le rendant ainsi bien plus lisible et plus facile à vérifier. Deux fils qui ont le même nom de Net sont considérés reliés entre eux.


Pour ajouter un fil on clique sur le petit symbole de la barre en haut, et ensuite on clique sur Wire ou on appuie sur entrée pour poser le fil, et échap ou clic droit pour arrêter de le poser et pouvoir continuer plus loin. Pour ajouter un net on clique sur Net Label puis sur le fil que l’on souhaite associer à ce net. Pour arrêter de placer des fils ou des nets, il faut appuyer sur echap ou cliquer droit. Pour modifier le nom d’un net on double clique dessus.

Il existe deux types de net spéciaux : la masse, et l’alimentation. Si dans notre schéma, on a plusieurs masses et/ou plusieurs alimentations, on peut changer leur nom, toujours avec un double clic, et les renommer en par exemple 5V et 3V pour l’alimentation. Pour éviter de renommer tous les nets à la main, on peut les copier une fois le premier posé et renommé. Que ce soit pour les fils ou les nets, il faut bien faire attention à relier ce qu’on veut relier ensemble en cliquant au bon endroit (Tips : s’aider des croix qui deviennent rouges quand on fait une connexion).

Si trois fils sont reliés au même endroit, Altium fera apparaître un rond bleu à la jonction. (Tips : Cela peut paraître bête dit comme ça mais il est très facile de commettre une erreur à ce stade, alors il faut bien vérifier et ne pas hésiter à faire vérifier son travail une fois qu’on croit l’avoir terminé. Le risque est de s’en apercevoir bien plus tard et de devoir tout recommencer, il vaut donc mieux faire attention à ce stade.)

● Une fois que nos composants sont tous placés, il faut leur donner des noms explicites et uniques pour les identifier facilement par la suite. Ce nom est modifiable en double cliquant sur le composant puis en modifiant la case Designator de l’encadré Properties ou en double cliquant sur le schéma.

● En plus de l’utilisation de nets, on peut encore augmenter la clarté des schémas en séparant les blocs de composants par des traits et en ajoutant des commentaires pour chaque bloc. Pour ce faire, on utilise les cases Place Line et Place Text Frame que l’on trouve en haut à droite dans Utility Tools.


● Tout au long de la réalisation du schéma, il ne faut pas hésiter à sauvegarder son travail à l’aide du raccourci ctrl+s, ou dans File > Save All. Altium peut planter donc c’est vraiment important pour ne pas perdre son travail. Tout ce que Altium n’a pas enregistré est matérialisé par une * à côté de son nom, avant de passer à la suite, pensez à bien tout enregistrer.

● Tips final : Et pour finir, le point le plus important pour cette étape : il est tout à fait possible et recommandé de réutiliser ce que les autres ont fait avant vous (si ça marchait bien sûr). Le copié collé de contenu de schéma d’un workspace à l’autre est possible.

II - c. PCB

Créer un PCB (fichier .PcbDoc)

L’étape suivante est à faire à chaque nouvelle carte !

● Vérifier que l’on se trouve bien dans les workspace et projet dans lesquels se trouve le schéma électrique que l’on veut transformer en PCB, et changer si ce n’est pas le cas. Pour vérifier, on regarde ce qu’il y a écrit dans l’onglet Projects dans les cases à gauche de Workspace et Project.

● Clic droit dans le milieu de l’onglet Projects > Add New To Project > PCB

● Clic droit sur le nom du pcb dans l’onglet Projects > Save As > Enregistrer le pcb que l’on vient de créer à l’endroit proposé, avec un nom explicite.

● File > Save All

On a maintenant notre fichier pcb sur lequel on va placer chaque composant de notre schéma électrique (le fichier .SchDoc créer juste au-dessus) et les relier entre eux avec des fils cette fois. A nous d’optimiser l’agencement pour que tout rentre avec les contraintes de dimensions de la mécanique et de faire en sorte que tout soit relativement simple d’accès (pas de bouton dessous par exemple💀)

Un fichier PCB est compris de plein de Layer différents (on en voit certains sur l’image dessous – cette barre se trouve en bas du logiciel lorsqu’on ouvre un fichier .PcbDoc) et ceux qu’on utilise sont les suivants :

- Top Layer : Couche qui contient les connexions du dessus
- Bottom Layer : Couche qui contient les connexions du dessous
- Mechanical : La documentation, les dimensions, les contours
- Top / Bottom Overlay : Les annotations que l’on met sur la carte

Réaliser un PCB à partir du schéma électrique

● La première étape consiste à “importer” dans le PCB le contenu de notre schéma électrique. Cette étape est à faire juste après la création du fichier PCB mais aussi après chaque mise à jour du schéma électrique. Pour cela, on ouvre le schéma et dans la barre du haut, on clique sur Design > Update PCB Document Name.PcbDoc. La fenêtre suivante montre ce qui va être ajouté ou enlevé du PCB, et prévient d’éventuelles erreurs. Si tout est cohérent et qu’il n’y a pas d’erreurs, cliquer en bas sur Validate Changes puis Execute Changes et enfin Close. Les composants ajoutés sont apparus à la droite du PCB dans le fichier .PcbDoc, que l’on peut sauvegarder avec ctrl+s.

● Dans le cas où l’on connaît la taille exacte ou approximative du PCB que l’on souhaite réaliser, il faut commencer par régler cela. Sinon cela peut attendre la fin du placement, et on se reportera alors à ce point. Avant toute chose, on va passer le design en unité métriques : depuis la page du PCB, clic droit > Preferences > Schematic > General et tout en haut à gauche on choisit Millimeters. On doit aussi choisir la précision avec laquelle on veut pouvoir choisir la taille du PCB, on se place la souris sur le PCB puis on appuie sur G et enfin la résolution choisie (par exemple, 1mm) | Sinon le raccourci clavier est Q pour changer d’unité, on peut le vérifier en bas à gauche de l’écran.

Puis, on va placer l’origine en bas à gauche du PCB en la rendant déplaçable à l’aide de Edit > Origin > Set. Pour ajuster la taille du PCB, on se place dans un nouveau mode en cliquant sur View > Board Planning Mode | Raccourci clavier est la touche du 1. Ensuite, on clique sur Design > Edit Board Shape et on peut déplacer l’extrémité de droite et du haut de notre rectangle par rapport à l’origine, pour atteindre la taille voulue (que l’on peut lire avec les coordonnées de notre pointeur si l’origine est bien placée). Pour avoir des coins arrondis (c’est mieux, sinon le PCB est un peu dangereux), on en sélectionne un toujours en mode édition (Design > Edit Board Shape) et on appuie deux fois sur shift+space pour passer en mode arrondi. Une fois la forme du PCB définie, on peut repasser en mode de vue normal en cliquant sur View > 2D Layout Mode | Raccourci clavier est la touche du 2.

● On veut maintenant placer les composants sur notre PCB. On commence par placer au centre du PCB les composants qui ont le plus de “pattes” utilisées, car ce seront les plus difficiles à router. Ensuite, on arrange les autres composants autour de manière que tous les pins qui doivent être reliés entre eux ne soient pas trop loin les uns des autres. Pour tourner un composant, on appuie sur espace en l’attrapant sans le lâcher. Pour rendre cette tâche réalisable, il est important de remarquer que les pins des composants qui doivent être reliés entre eux le sont par de fines lignes blanches vers le(s) voisin(s) le(s) plus proche(s). En zoomant sur les pins, on peut aussi voir le nom des nets en question. Aussi, par défaut, tous les composants sont placés sur le dessus de la carte, mais on peut aussi les placer en dessous par exemple si on manque de place sur le dessus. Pour faire cela, on double clique sur le composant depuis le PCB et dans l’encadré Component Properties en haut à gauche, case Layer, on sélectionne Bottom Layer au lieu de Top Layer. Le préplacement réalisé à ce stade peut être évidemment amené à changer lors de la prochaine étape.

● Une fois les composants placés, il faut les relier entre eux. C’est ce qu’on appelle le routage, et c’est l’étape la plus compliquée car il faut respecter un grand nombre de bonnes pratiques et contraintes :

- On doit relier tous les nets entre eux, sauf la masse (ou une des masses s’il y en a plusieurs).


- Pour tracer les pistes conductrices reliant les composants entre eux, on clique Interactive Routing sur la barre du haut | Le raccourci clavier est ctrl+w. Mais il faut savoir que l’on peut (et doit) régler leur largeur. En effet, si les fils sont trop fins comparé à la quantité de courant qui les traversera, ils vont devenir très chaud, ce qui peut endommager les composants où brûler des doigts.

Pour calculer la largeur recommandée des pistes en fonction du courant, je recommande ce site (https://www.digikey.fr/en/resources/conversion-calculators/conversion-calculator-pcb-trace-width). (Tips : De manière générale, seuls les pistes logiques peuvent garder la largeur par défaut de 0.254mm. Les pistes de puissance (moteurs notamment) doivent être bien plus larges, 1.5mm idéalement). Pour changer la largeur des fils, il existe deux options : soit on double clique sur chaque fil après l’avoir tracé pour changer sa largeur à posteriori, soit on change la taille des fils par défaut en allant dans Design > Rules… > Routing > Width > Width et en changeant la valeur de Preferred Width à la nouvelle. Dans les deux cas, il faudra changer la valeur de Max Width en dessous pour s’adapter à la nouvelle largeur maximale des pistes sur le Top Layer et le Bottom Layer.

- Ensuite, il faut garder en tête que les pistes ne peuvent pas se croiser (et c’est ça qui rend le routage si difficile). Cependant on peut utiliser des vias (des trous conducteurs qui traversent le pcb), et réaliser le croisement en utilisant des fils sur le côté opposé du pcb. (Tips : Ces vias sont à utiliser le moins possible, si on en a besoin de beaucoup c’est que le placement des composants est à revoir). Les vias sont ajoutées grâce à l'icône Via de la barre du haut, et ensuite il faut double cliquer dessus pour les associer au Net voulu. (Tips : Il est important de remarquer que les trous des pattes des composants qui traversent le PCB se comportent exactement comme des vias, ce qui peut permettre de passer sur la couche opposée sans avoir à rajouter de vias).
- Lorsqu’on trace des pistes sur le pcb, on évite de faire des angles droit ou aigus avec, et on évite aussi d’enchaîner les virages si ce n’est pas nécessaire.
- Pour tracer des pistes sur le dessous du pcb il suffit de sélectionner Bottom Layer dans le bandeau du bas avant d’utiliser l’outil de routage.

● Pour la masse, on utilise un plan de masse pour relier les différents pins entre eux. Cela permet de faire en sorte que toute la surface de notre carte, à l’exception des connexions, est relié à la masse. On évite donc de relier les masses entre elles. Si tous nos composants sont sur la couche supérieure, un plan de masse sur cette dernière suffit. Sinon, on en place un sur la couche supérieure et un sur la couche inférieure, et on les relie à l’aide de vias pour améliorer leur connexion. Pour placer un plan de masse, on clique sur Place > Polygon Pour, puis on choisit la couche et le net auquel on veut relier ce plan (donc la masse - GND) et on trace le plan de manière à couvrir toute la surface où se trouvent des composants (reliés à la masse au moins, mais tous c’est plus joli).

● Si les trous de vis n’ont pas été pris en compte dans le schéma électrique, il faut penser à les rajouter maintenant. Je recommande de regarder les pcb des années précédentes pour connaître le type et surtout la taille des trous à faire – Un copier-coller suffit amplement sinon ils sont dans la librairie Robot_2020.PcbLib et se nomme Screw M3.

● On peut aussi ajouter du texte sur le pcb à ce stade. Il est important d’écrire le nom de la carte (à quoi elle sert), la version, l’année, le logo du club … Pour cela, on sélectionne la couche Top Overlay (ou Bottom Overlay pour le dessous) dans le bandeau du bas, puis dans la barre du haut on clique sur String. Un fois le mot String placé, on peut double-cliquer dessus pour modifier le texte mais aussi la police et la taille.

Aussi, si les footprints n’étaient pas très clairs, il est possible de rajouter des détrompeurs ou une légende à côté de certains composants. Pour tous les connecteurs auxquels on viendra brancher des fils, il est très fortement recommandé d’écrire à côté de chaque pin le nom simplifié du net auquel il est relié, sinon le câblage du robot devient vite un enfer et on peut commettre des erreurs.


On a aussi l’habitude de rajouter le logo du club. Pour l’ancien logo, il faut cliquer sur Component…, puis sélectionner la footprint du logo dans la librairie Robot_2020.PcbLib et il s’appelle Logo_lowres.

● Finalement, on vérifie s’il y a des erreurs sur notre PCB, en faisant Tools > Design Rule Check > Run Design Rule Check…. Certaines erreurs ne sont pas très importantes (par exemple, toutes celles qui contiennent le mot Silk concernent les couches d’overlay donc ne sont pas critiques), mais il faut bien vérifier que toutes les erreurs trouvées rentrent dans cette catégorie avant de passer à la suite.

III. Commande du PCB (sur JLCPCB)

● Pour éviter de se faire gronder à la commande, il faut rajouter une ligne qui fait le tour de la carte dans la couche Mechanical 1 par exemple. Il y a peut-être une manière automatisée de le faire mais je ne l’ai pas trouvé, alors ma technique consiste à me placer sur cette couche puis à aller cliquer sur Place > Line, puis de faire le tour du PCB avec cette ligne.

● Ensuite il faut exporter les bons fichiers au bon format : cf ce site (https://jlcpcb.com/help/article/How-to-export-Altium-PCB-to-gerber-files) (https://jlcpcb.com/help/article/How-to-export-Altium-PCB-to-gerber-files | https://www.altium.com/documentation/altium-designer/preparing-fabrication-data)

● Une fois tous les fichiers récupérés, les zipper ensemble

● Et enfin il ne reste plus qu’à commander sur le site (https://jlcpcb.com/) (https://jlcpcb.com) à l’aide de ce zip

IV - a. Librairies & Composants

● On utilise 3 librairies principales pour le club :

- Robot 2020 pour les composants beaucoup utilisé au club (Résistance, Condensateur, Teensy, convertisseur de tension, Fusible, Drivers, Led, le logo, Molex, Header, Néopixels, Optocoupleurs)
- Miscellaneous Device pour les composant classique (Diodes, Led, etc)
- Miscellaneous Connectors pour toutes sortes de connecteurs
- Samacsys pour les composants importés par le gestionnaire externe (Connecteurs coudés).

● Si un composant que l’on souhaite ajouter est nouveau et/ou ne se trouve pas dans les librairies du club, il faudra l’ajouter à la main. C’est tout à fait possible mais là pas de guide ici, google sera votre allié.

● Références des composants :

- Résistance CMS : Resistor 1206
- Condensateur CMS : Capacitor 1206
- Condensateur traversant : Condensateur
- LED : KP-3216SEC
- Trou de vis : Screw M3
- Driver Stepper : DRV8825 (Moteur pas-à-pas)
- Driver Dual Motor : L293D (Moteur DC)
- ESP32 : Module_esp32 (Dépend du modèle de l’esp)
- Teensy :
- Optocoupleurs : LTV-247 ou le FOD817S

IV - a. Tips Altium

● Lien vers la vidéo qui a permis de réaliser une partie de ce document (merci les VieuxA) : https://www.youtube.com/watch?v=6N2A6LtBWh0

● Lorsqu’un composant est sélectionné sur un schéma, on peut le faire tourner d’un quart de tour en appuyant sur la barre espace

● Sur les fichiers PCB :

- 1 - 2 - 3 permettent de changer de vue (Planning Mode | 2D | 3D)
- Q permet de changer l’unité (système métrique – impérial)
- G permet de modifier la taille de la grille
- Ctrl+w permet de créer une connexion
- Ctrl+c / ctrl+v permet de copier puis coller un composant ou une sélection

● Sur les fichiers Schéma :

- Ctrl+w permet de créer un fil

● Avoir une souris :

- Pour zoomer/dézoomer sur un schéma ou un PCB, on utilise ctrl+molette
- Pour aller de haut en bas sur un schéma ou un PCB, on utilise la molette
- Pour aller de gauche à droite sur un schéma ou un PCB, on utilise shift+molette

● Signification de la couleur de ce qu’on voit sur le PCB :

- Le grand rectangle noir correspond au PCB
- Tout ce qui est rouge va correspondre aux zones conductrices (pads ou trous pour souder les composants ou fils conducteurs) de la couche du dessus. Idem pour le dessous mais en bleu.
- Tout ce qui est violet correspond à la projection de la forme des composants physiques que l’on viendra souder sur notre PCB.
- Tout ce qui est jaune correspond à ce que l’on va imprimer sur notre PCB (le nom des composants, des détrompeurs, d’éventuels commentaires ou dessins, et plein d’autres)
- Si l’on voit apparaître des petites croix vertes c’est que l’on a mis trop proche ou superposé deux choses incompatibles, et qu’il faut donc déplacer un des composants en cause

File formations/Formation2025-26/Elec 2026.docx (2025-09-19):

Club Robotik : Formation Altium

I - Composants principaux

Avant de faire des circuits électriques, il faut savoir quoi brancher dessus et donc connaître les composants existants. Ici on voit les plus importants actionneurs, capteurs, et contrôleurs du club :

Servomoteur MG995: Durabilité et Performance Optimisées

Servo moteur Microcontrôleur

Contrôle moteur avec un pont en H
Contrôle d'un moteur CC – Arduino : l'essentiel

Moteur CC Ponts en H

Ce sont des exemples, il y en a d’autres (moteur pas à pas, optocoupleurs, level shifters, etc…). On en couvrira certains avec leurs utilités, conditions d’utilisations, points forts, points faibles, et autres informations utiles. Ce recueil a pour but d’être un guide d’introduction – n’hésitez donc pas à le compléter si vous utilisez d’autres composants, des pompes ou des électroaimants par exemple.

Servo moteur : Un petit moteur électrique permettant d’aller à une position angulaire précise. Permet de maintenir en place un composant avant de le relacher par exemple.

Comprant un asservissement précis à l’ordre du degrès près.

Se connecte avec 3 cables (Rouge - VCC, Noir/Marron - GND, PWM).

Le signal PWM permet d’envoyer la position voulue (Course entre 0° et 180°) au servo à l’aide d’un code C++. Ca position est également renvoyé par le PWM au microcontroleur. Cela implique de le connecter à une pin du microcontroleur permettant le IN et le OUT.

On peut également interposer un optocoupleur (ou photocoupleur) entre le microcontrôleur et le servo sur la connexion PWM. Il s’agit d’un composant permettant d’isoler le microcontrôleur des pics de tensions, des courants de retours, ainsi que des bruits électriques. En gros, c’est une protection pour le microcontrôleur.

P.S : l’optocoupleur n’est pas super utile pour un servo mais ça ne fait pas de mal

Moteur CC (ou DC) & Ponts en H : Vos cours de prépa sur les moteurs à courant continu. On alimente dans un sens ce qui fait tourner des aimants et crée un couple.

Les ponts en H sont de simples circuits électriques composés de 4 interrupteurs permettant de changer le sens du courant – ils permettent ainsi de contrôler le sens de rotation de ces moteurs.

Ils offrent une rotation continue avec une course >360° (contrairement au servomoteurs) dont le couple, et donc la vitesse, dépendent de la tension.

Il possède deux connexions – Le GND et le VCC i.e. la masse et l’alimentation.

Au club, on utilise le composant L293D qui est un double pont en H – il permet de contrôler deux moteurs à la fois - utile pour des robots à 2 roues ;).

On peut également interposer un optocoupleur entre le microcontrôleur et la partie puissance (pont en H + moteur).

Moteur Pas à Pas 2.25 Vdc ref.KP6M2-010

Moteur pas à pas (Stepper) : Moteur électrique qui divise une rotation complète en pas discrets. Chaque impulsion fait donc tourner le stepper d’un pas (ex : 1,8° par pas -> 200 pas/tour). Le moteur tourne par “sauts” successifs plutôt que de façon continue et à une course >360°.

Il est donc plus simple de contrôler la position d’un stepper que d’un moteur DC en revanche le couple est souvent limité à haute vitesse comparé au moteur DC.

Il possède 4 connexions – 2 pour chaque bobine que l’on relie à un driver. En effet, il nécessite un driver pour être contrôlé (DRV8825 au club par exemple). C’est un composant qu’on intègre sur la carte électronique entre le microcontrôleur et le stepper.

Il est également conseillé d’interposer un optocoupleur entre le microcontrôleur et le stepper.


Microcontrôleur (Pôle info pour plus de détails) : On utilise principalement les 3 de la photo au club à savoir – dans l’ordre – les Raspberry Pi Pico, les Esp32, et les Teensy.

Ces composants sont des mini-ordinateurs autonomes qu’on peut programmer afin de contrôler des actionneurs ou lire des données capteurs à l’aide de leurs nombreux pins.

! L’important à savoir est que tous les pins ne sont pas égaux, certains ont des fonctions particulières (GND, VCC, etc…), d’autres permettent uniquement d’envoyer ou de renvoyer des données, d’autres les deux, etc. Il faut toujours se référer à la « pin layout » de chaque microcontrôleur avant de créer une connexion !

Les Teensy :

Un microcontrôleur très puissant et très rapide surtout. Utile pour les projets en temps réel. On utilise les 4.0 au club, fonctionne en 3,3 V et se programme en C++ (ou Arduino)

Les Esp32 :

Un microcontrôleur un peu moins puissant mais possédant le Wifi / Bluetooth et permettant de faire du multitâche. On utilise les Esp32 DevKit v1, fonctionne en 3,3 V et se programme en C++ (ou MicroPython ou Arduino).

Le DevKit correspond à la carte de développement autour (avec le port usb, des régulateurs de tensions, boutons EN & BOOT, des leds, etc) – l’esp32 correspond à la puce (WROOM32, H2, S3 …) qu’il est impossible de manipuler seule.

Les Raspberry Pi Pico :

Un microcontrôleur encore un peu moins puissant que les esp32 mais avec un prix très faible. Fonctionne en 3,3 V et se programme en C++ (ou MicroPython)


Les optocoupleurs (ou photocoupleurs) : Vu que j’en ai parlé plus haut, les voilà.

Composant électrique permettant d’isoler deux circuits puis éviter que le bruit ne se propage, qu’il y ait des courants de retour, ou encore des pics de tension.

Très utile avec les moteurs comme précisé plus haut

Concrètement, une Led infrarouge s’allume lorsque le courant passe. Cette onde est captée par le phototransistor ce qui induit un courant dans le circuit de sortie sans aucune connexion entre les deux.

En conclusion, ils existent plein de composants – électriques comme mécaniques – différents, chacun avec sa propre utilité. Le mieux est de se renseigner et d’utiliser les datasheets des composants pour choisir le bon et ensuite le brancher correctement !

II - Protocoles de communications

Après savoir quels composants existent, il est utile de savoir comment ils communiquent entre eux : C’est le principe de ces protocoles de communication.

On verra ici les principaux à savoir : l’UART – l’I²C – le SPI – l’USB que vous connaissez déjà.


Tour d’abord, du vocabulaire : série / parallèle et synchrone / asynchrone.

Dans une communication série, chaque bit est envoyé l’un après l’autre ce qui rend la communication plus lente mais avec moins de fils. Contrairement au parallèle qui envoie plusieurs bits en même temps sur des fils différents


Dans une communication synchrone, un fil supplémentaire correspond à l’horloge permettant de synchroniser les deux composants. Celle du maitre est utilisé.

Dans une communication asynchrone, chaque signal contient des bits de synchronisation avant chaque paquet afin que les composants soient malgré tout synchronisés.

Maintenant, les protocoles :


L’UART (Universal Asynchronous Receiver/Transmitter) : Protocole de communication série asynchrone utilisé pour transmettre des données entre deux appareils via seulement deux fils : un pour émettre (TXD) et un pour recevoir (RXD).

Très simple mais ne permet que deux appareils contrairement à l’I²C ou SPI.

Est très lent (max 100 kbits/s) mais utilisé pour programmer des contrôleurs par exemple.

! On connecte bien le TXD de l’un au RXD de l’autre et vice versa !


I²C (Inter-Integrated Circuit) : Il s’agit d’un bus de communication série synchrone permettant à plusieurs composants de communiquer via 2 fils.

Un maître communique avec plusieurs esclaves à l’aide d’une adresse sur 7 bits modifiable.

Plus rapide (400 Kbits/s) que l’UART mais plus complexe et plus lent que SPI. Fonctionne sur des faibles distances.

! Important : Mettre des résistances de pull up entre 4 et 10 kΩ sur les lignes sda (serial data ligne – les données transmises en série) et scl (serial clock line – l’horloge) !


SPI (Serial Peripheral Interface) : protocole de communication série synchrone conçu pour des échanges entre un maître et plusieurs esclaves.

Fonctionne sur 4 fils: MOSI (Master Out Slave In) – MISO (Master In Slave out) – SCK (Serial Clock Select) – SS (Slave Select). SS nécessite une résistance de pull up.

Beaucoup plus rapide (centaines de MHz) mais nécessite plus de pins.

- À chaque front d’horloge, 1 bit est échangé entre maître et esclave (plein-duplex).
- Les données sont échangées bit par bit en parallèle sur MOSI et MISO.
- Le SS (chip select) est utilisé pour activer un esclave à la fois (à LOW).


Si la distance est trop grande ou la vitesse est trop élevé (USB), il faut faire de l’adaptation d’impédance – 50 Ω en général.

Permet d’éviter les ondes réfléchies et donc les signaux stationnaires (cours de prépa).

PWM (Pulse Width Modulation) : Technique de modulation qui permet de simuler une tension analogique avec un signal numérique.

Il génère un signal carré (0 ou 1) à fréquence fixe, mais fait varier le rapport cyclique (durée de l'état haut). Très simple à générer sur un Esp32 et donc très utilisé pour des servomoteurs, des leds, des moteurs, etc…

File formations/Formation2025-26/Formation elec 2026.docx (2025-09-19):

Club Robotik : Projet Formation

I. Altium
  a. C’est quoi ?
  b. Installation
  c. Github & Librairies
II. Projet Formation
  a. Matériels & Sécurité
  b. Souder carte superstar

I - a. Altium, c’est quoi

Altium est un logiciel complexe permettant de créer ses propres cartes électroniques : des schémas, des pcbs, le routage, la visualisation 3D, etc.


Ca c’est l’architecture électrique type de nos robots, c’est toujours la première étape avant de créer des cartes. On y met tous les composants qui se trouveront sur notre robot regroupé en plusieurs groupes qui donneront chacun une carte différente : L’alimentation, la propulsion, et enfin les actionneurs.


Après l’architecture, on passe au schéma électrique qui détaille les composants (il existe des dizaines de référence pour faire la même chose, lequel on prend ?) et toutes les connexions entre les composants.


Ça, ce sont les PCB. Après le schéma, on choisit où on les placer sur la carte et par où faire passer les fils.

Vue 2D Vue 3D et finale


Ensuite on commande le PCB au fabriquant et on reçoit ça : Une carte avec toutes les connexions de faites mais aucun composant


La dernière étape est donc de souder tous les composants sur la carte pour avoir la version finale.

I - b. Installation d’Altium

Se référer au fichier : Tutoriel installation Altium Designer 2024.pdf - fais par un super 3A Thomas Roberge ;)

I - c. Github et Libraires

Le pôle électronique à un github (aller voir la formation github du pôle info pour plus de détails) que vous retrouverez ici : https://github.com/Jean-Michel-Robot/Elec2024-25. Cloner tout sur votre machine.

Vous devez ainsi avoir un dossier Elec2025-26, un libs, un old_repos.

Elec2025-26 contiendra tous les fichiers de l’année que vous allez créer. Le dossier libs contient toutes les librairies avec tous les composants utilisés par le club. Et old_repos contient les cartes des années précédentes (elles vont être très utiles).

Installation des librairies du club (fichier .PcbLib & .SchLib & .IntLib)

L’étape suivante n’est à faire qu’une seule fois ! (Normalement)

Maintenant, on doit installer ces librairies sur Altium avant de commencer à travailler sur un projet. Il semblerait que les librairies soient liées à Altium et non un workspace en particulier donc il n’y a pas besoin de refaire la manipulation lorsque l’on change de workspace ou de projet

● Dans Altium, ouvrir l’onglet librairies en cliquant sur View > Panels > Components > > librairies preferences

● Cliquer sur la case Add Librairies en bas à droite de l’onglet librairies

● Sélectionner avec Ctrl+A tout le contenu du dossier libs provenant du Github puis cliquer sur ouvrir et quitter la fenêtre

Okayy, on a fini avec l’installation d’Altium et on ne va pas l’utiliser plus que ça dans cette formation. Vous découvrirez le logiciel quand vous ferez des cartes dans l’année et vous avez aussi un document qui explique tout ce dont vous avez besoin pour utiliser Altium.

La suite est maintenant que de la pratique ! Vous n’aurez plus besoin d’Altium à partir de maintenant dans cette formation.

II - a. Matériels et Sécurité

Station de soudage Weller, WE 1010, 70W, 230V, 1 sortie(s) , prise Schuko + UK

Souder, ça permet de créer un contact électrique entre un composant et une piste en cuivre d’un pcb.

Pour ça, on utilise de l’étain qu’on fait fondre à l’aide d’un fer à souder : ce truc →

On chauffe à 400°C donc, avant de souder, il y a des règles à respecter :

- On dégage le plan de travail afin de ne rien brûler avec la panne (la partie qui chauffe)
- On garde uniquement la lampe qui va permettre d’éclairer notre pcb

6 pinces ESD - Fer À Souder Électrique À Température Réglable 60w 220v ...

- On fait attention à ce que la panne ne touche JAMAIS le câble d’alimentation du fer
- Quand on soude, on utilise les pinces de l’élec pour maintenir les petits composants en place ainsi que la 3ème main afin de pas se brûler les doigts et la loupe pour ne pas se niquer les yeux.
- On évite de respirer les fumées dégager par la soudure, surtout si l’étain contient du plomb
- On remet toujours le fer à souder dans son support, on ne le laisse pas traîner sur le plan de travail
- On éteint toujours le fer quand on a fini de l’utiliser

Pistolet-air-chaud-858D-700W-BGA-station-de-soudure-220V-110V-pour-r ...

Moins utilisé que le fer, on a un pistolet à air chaud.

Il est surtout très utile pour les gaines thermo rétractables qui permettent de connecter proprement deux câbles. L’air n’est pas suffisamment chaud pour bruler mais on fait quand même attention.

Fluke 115 EUR 115 True RMS Digital Multimeter - Black Buy, Best Price ...

Enfin, le multimètre. Bon vous connaissez, on l’utilise surtout pour vérifier la qualité des soudures avec le mode continuité qui fait bip bip si le courant passe i.e. la soudure est bien faite.

II - b. Carte Superstar

On va vous donner un pcb vierge d’une des cartes de l’année dernière que vous allez devoir souder. Pour cette fois, on vous donne le schéma et le pcb fini mais voici une idée des étapes avant d’y arriver :

1. On réalise l’architecture électrique du robot qui sera autonome. On liste ce qu’il devra faire, dans notre cas :
  a. Se déplacer et connaître sa position
  b. Détecter la présence d’obstacles devant lui
  c. Avoir un actionneur quelconque qui devra être visible par les spectateurs
  d. Posséder un bouton d’arrêt d’urgence (BAU) et un bouton ON/OFF
  e. Posséder une tirette
  f. Avoir deux stratégies différentes

Pour ça, on utilise donc un capteur ultrason pour les obstacles, des moteurs DC ainsi que des encodeurs pour la position. On ajoute un bumper pour la tirette, un BAU, un bouton ON/OFF, un servomoteur, et un *j’ai plus le nom* pour changer de stratégie.

2. On conçoit le schéma électrique correspondant sur Altium en choisissant les composants qui conviennent / que le club possède.
3. On crée le PCB sur Altium en positionnant les composants et créant les connexions.
4. On commande et on reçoit ce qu’on va vous donner


Vous allez tous avoir un truc qui ressemble à ça (pas exactement le même).

Vous allez maintenant souder tous les composants pour faire vivre cette carte :

1. Ouvrir le schéma sur Altium :
  a. Ouvrir le fichier ELEC_24-25.DsnWrk avec Altium.


  b. Double cliquer sur SchemaSuperstar.SchDoc et sur PCB_pami_superstar.PcbDoc dans la barre des Projects afin d’ouvrir deux onglets :
2. A droite on a le schéma : Un fichier nous montrant quels composants sont présents sur notre carte ainsi que comment ils sont reliés entre eux.
  a. Pour la lisibilité, on ne relie pas tous les fils. On utilise des nets : Deux fils portant le même nom sont des « Nets » et agissent comme s’ils étaient reliés. (Allez voir le tuto Altium pour plus de détails)
3. A gauche, on a le pcb en 2D (on peut appuyer sur la touche du 3 pour la vue 3D) : Un fichier qui indique où sont placés les composants sur notre pcb et comment ils sont reliés entre eux.

Vous allez maintenant utiliser ces deux fichiers afin de souder tous les composants sur votre pcb vierge. On n’oublie pas les règles de sécurité ainsi que les conseils de la partie précédente.

4. On commence par souder les composants de surface qui ne vont pas nous gêner ou prendre de la place (résistances, condensateurs, LED, etc…)
  a. Tous les composants sont disponibles dans la tour à gauche du bureau de l’élec – demandez aux 2A/4A si vous ne trouvez pas. Prenez uniquement la quantité dont vous avez besoin.
  b. Soudez un par un chaque composant – si vous ne reconnaissez pas le symbole du composant sur le schéma, on peut double-cliquer dessus pour avoir accès aux détails comme sa référence et une image 3D. Sa référence et une recherche internet permettent de tout savoir sur lui.
  c. Après chaque soudure, on utilise le multimètre en mode continuité pour vérifier que la soudure est efficace, que le courant passe bien
5. Soudez tous les composants un par un, d’abord ceux de surface puis les plus gros (fusible, teensy, connecteurs, etc)
6. On teste toutes les soudures au multimètre si on ne l’a pas fait à chaque fois

Si vous avez fini assez vite, il existe plein de petite manip utile à savoir faire qu’on ne détaillera pas ici, voyez avez les 2A pour des explications/demos afin de pouvoir le faire vous-même.

Par exemple : Les cartes de split, remettre un connecteur sur des fils, connecter deux câbles avec une gaine thermo rétractable, etc.

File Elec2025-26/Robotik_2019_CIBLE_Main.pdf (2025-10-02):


V 2 | Robotik 2019 – ELEC – Cible Main | 1

## CIBLE MAIN DATASHEET

INTRODUCTION

Cette carte permet de commander la PMI de la coupe 2018.

Elle permet :
- De commander des Dynamixels
- De récupérer l’informations de 4 sonars
- De se connecter à une IMH
- De commander une sortie supplémentaire

Elle est basée autour d’un microcontrôleur « Teensy 2.0 ».

DESCRIPTION DETAILLÉE

Cette carte est faite pour être utilisée seule. Elle possède donc un étage de conversion de tension avec un fusible de protection de batterie (maximum 3A), et deux convertisseurs de tension (TSR1 pour générer le 5V logique, TSR2 pour générer le 12V actionneurs). Elle possède également deux voyants témoins associés aux convertisseurs. Au niveau logique, elle intègre 3 LEDs intelligentes (type Neopixels) et un slot pour la Teensy 2.0.

Attention : le 5V de la Teensy doit être séparé du 5V USB (pad à gratter).

Cette carte d’interface possède de nombreux branchements. Ils sont placés comme décrit sur la figure ci-dessous :

CORRESPONDANCES TEENSY

Les correspondances entre les sorties de la carte ou ses composants et les entrées/sorties du microcontrôleur sont les suivantes.

Composant | Signal | Pin | Remarque
ISB | DATA | 14
| LATCH | 13
| CLOCK | 12
| Neopixels | 11
Neopixels Carte | DATA | 2
Sonar 1 | ECHO | 21
| TRIG | 20
Sonar 2 | ECHO | 19
| TRIG | 18
Sonar 3 | ECHO | 4
| TRIG | 3
Sonar 4 | ECHO | 6
| TRIG | 5
Dynamixels | RX | 7 | Serial1 on Teensy 2.0
| TX | 8
| Control | 9
LEDs | DATA | 10

SCHÉMA ÉLECTRIQUE

COMPOSANTS


Les composants pour réaliser cette carte sont les suivants :

Identificateur | Reference | Référence RS | Nombre
U0 | Teensy 2.0 | 124-5526 | 1
| Support Traversant Femelle 2.54 | 401-699 | 2
U1 | SN74LS541DW | 526-492 | 1
F1 | 696101000002 | 893-0574 | 1
TSR1 | TSR 1-2450 | 666-4379 | 1
TSR2 | TSR 2-24120 | 906-8493 | 1
N1, N2, N3 | WS2812B | | 3
K1, K2 | OJ-SS-112LMH2 | 680-2518 | 2
D1, D2 | KP-3216SEC | 466-3891 | 2
R1, R2, R3 | SMD Resistor (package 3.2x1.6x1.1) | X | X
Header 2H (Molex SPOX) | 22-05-7025 | 687-8086 | 2
Header 3H (Molex SPOX) | 22-05-7035 | 687-8095 | 2
Header 4H (Molex SPOX) | 22-05-7045 | 687-8098 | 4
Header 6H (Molex SPOX) | 22-05-7065 | 687-8102 | 1

DÉTAILS MÉCANIQUES

Dimensions :
- | Longueur : | 90mm
- | Largeur : | 46mm
- | Hauteur : | 15mm
- | Fixations : | 4 vis M3 (diamètre 3.2)

REVISIONS


Version | Date | Modifications
V1 | 08/04/2019 | Version initiale
V2 | 22/04/2019 | Correction footprint TSR2 / Correction schematic relais / Changement U1

Auteur: Damien DESCLAUX

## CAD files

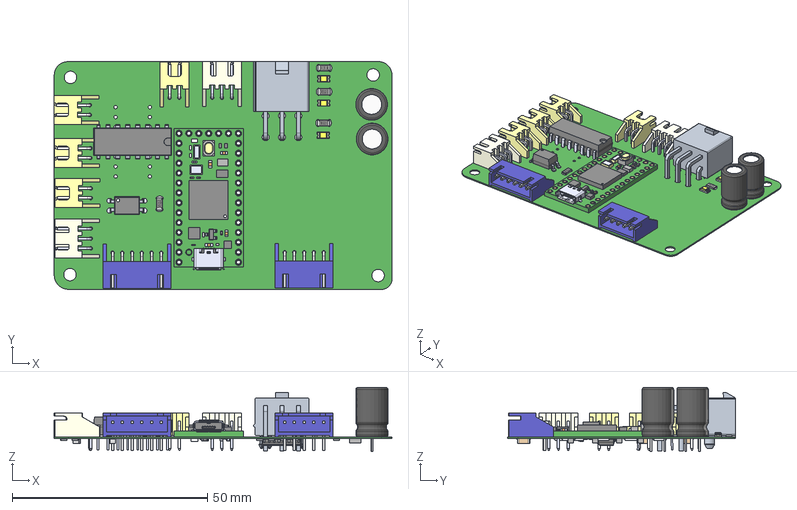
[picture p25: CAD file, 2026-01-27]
Elec2025-26/carte_action/carteAction2026v4.step
86.6 x 58.4 x 16.4 mm
res1206r x 16
CAPC1206 x 4
S2B-XH-A(LF)(SN)--3DModel-STEP-56544 x 4
LED 1206 Yel x 12
S3B-XH-A x 2
Extruded x 4
S5B-XH-A
S6B-XH-A
Leader x 16
DEV-15583 board
C5-C18 (0.55mm)
C20-C24 (0.65)
R1-R3 (0.4inch)_1269AS-H-3R3M=P2
L1^DEV-15583 ASS
C x 2
C2
Cond_100uF_50V x 2

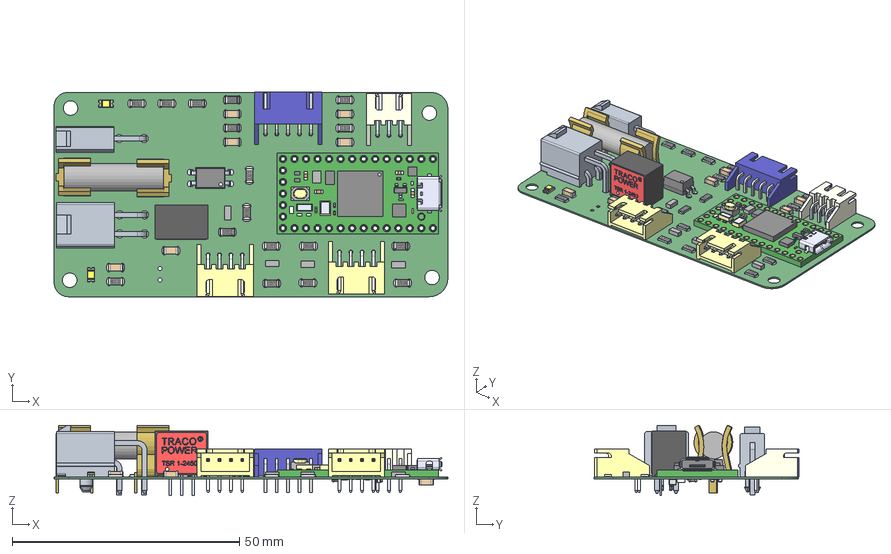
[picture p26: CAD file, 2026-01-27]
Elec2025-26/carte_propu/PCB_Propu2026.step
86.8 x 45.1 x 15.5 mm
res1206r x 17
CAPC1206 x 7
S5B-XH-A
Extruded x 4
DEV-15583 board
C5-C18 (0.55mm)
C20-C24 (0.65)
R1-R3 (0.4inch)_1269AS-H-3R3M=P2
L1^DEV-15583 ASS
C x 2
C2
TSR 1-2450 x 7
S3B-XH-A
S4B-XH-A x 2
FuseHolder x 2
LED 1206 Yel x 8

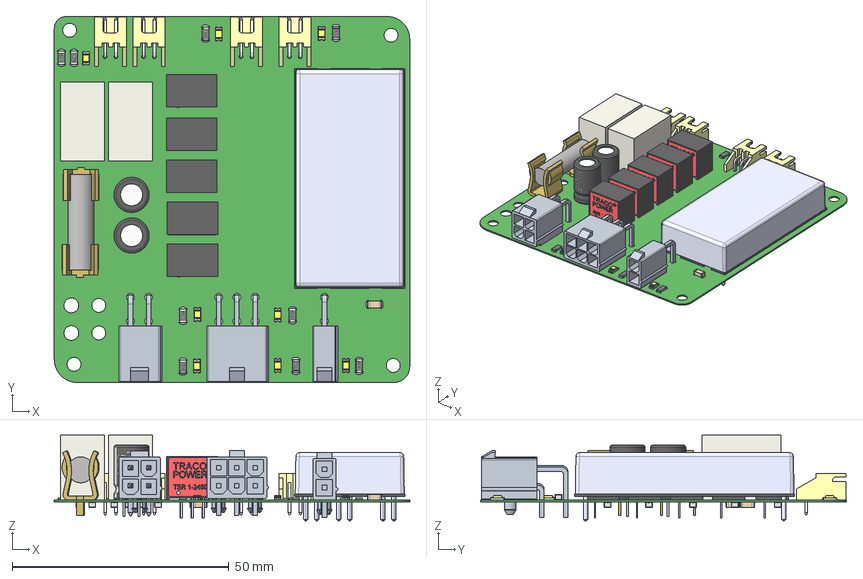
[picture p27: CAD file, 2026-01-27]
Elec2025-26/GR_Alim/GR_Alim2026.step
82.0 x 84.5 x 19.8 mm
S2B-XH-A(LF)(SN)--3DModel-STEP-56544 x 4
TSR 1-2450 x 35
res1206r x 9
Extruded x 2
FuseHolder x 2
LED 1206 Yel x 32
CAPC1206 x 12
Cond_100uF_50V x 2

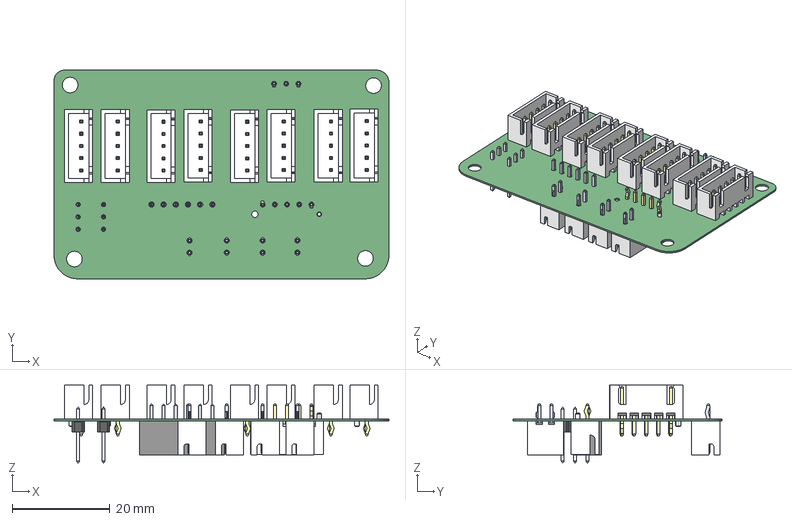
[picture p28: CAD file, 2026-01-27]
Elec2025-26/split_action/Split_action2026.step
68.7 x 42.8 x 16.0 mm
Pin Header 1x1 TH 2.54mm Pitch x 6
BxB-XH-A_02 x 4
LeadsArray

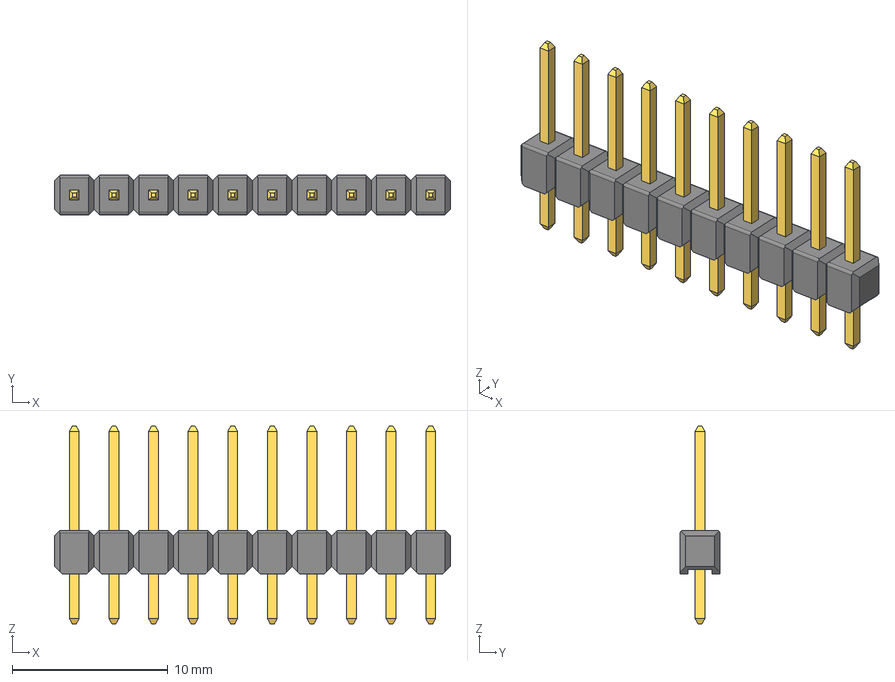
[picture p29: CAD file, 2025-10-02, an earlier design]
old_repos/Elec2019-20/Cartes/Custom/steps/Pin Header 1x10 TH Pitch 2.54mm.stp
25.4 x 2.54 x 12.7 mm

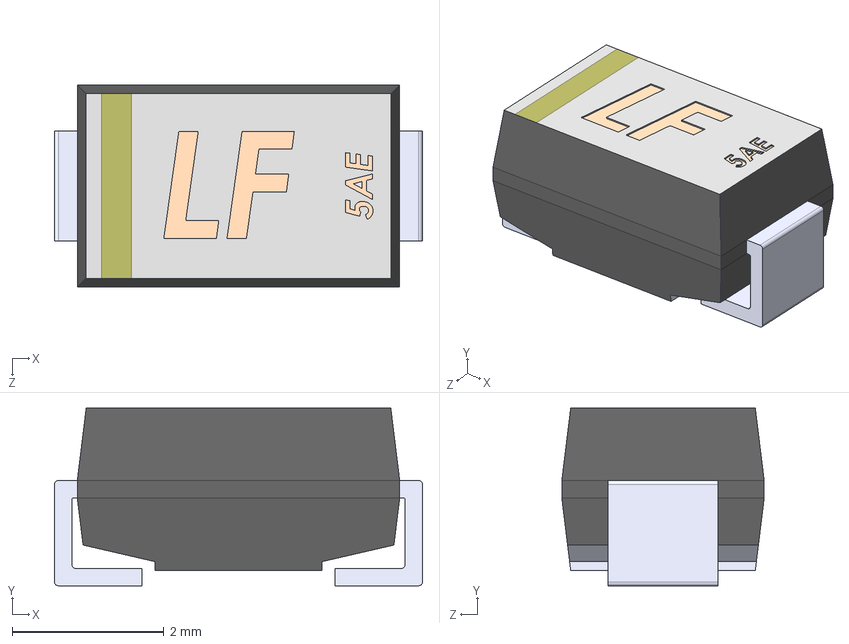
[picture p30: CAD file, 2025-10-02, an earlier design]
old_repos/Elec2019-20/Cartes/Custom/steps/diode_172mil.STEP
4.85 x 2.34 x 2.67 mm
diode_172mil
PIN_DIODE_172MIL x 2

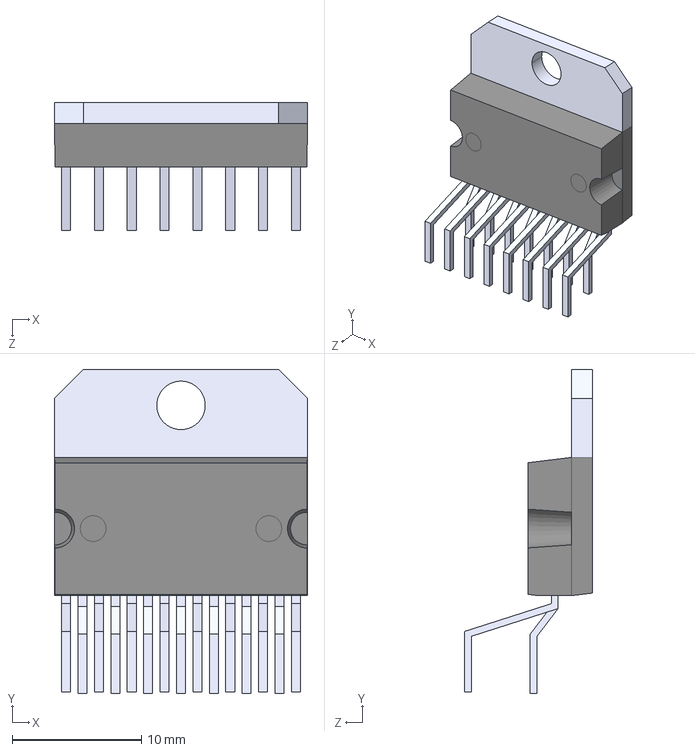
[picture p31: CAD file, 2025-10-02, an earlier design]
old_repos/Elec2019-20/Cartes/Custom/steps/L298_15P.STEP
19.6 x 25.1 x 9.89 mm

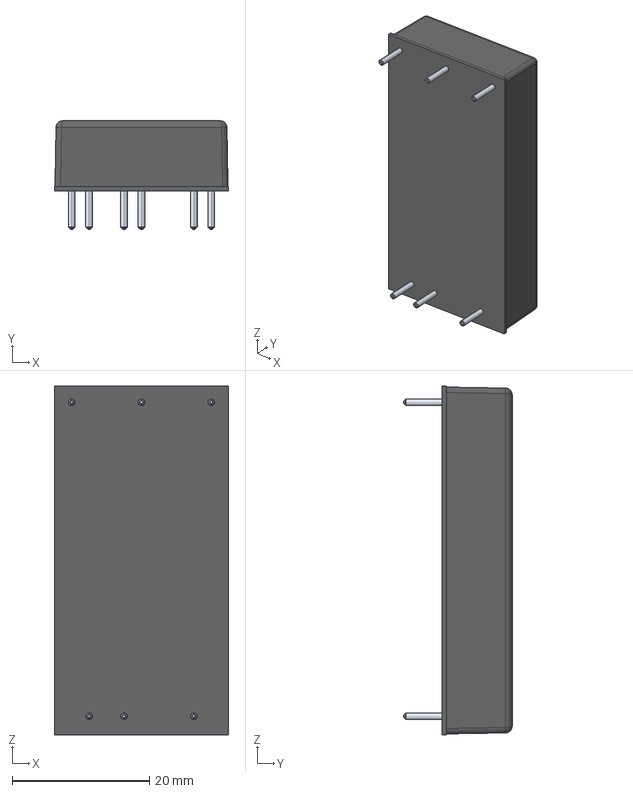
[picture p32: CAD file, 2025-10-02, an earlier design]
old_repos/Elec2019-20/Cartes/Custom/steps/Traco_2x1Inch.stp
25.4 x 15.8 x 50.8 mm

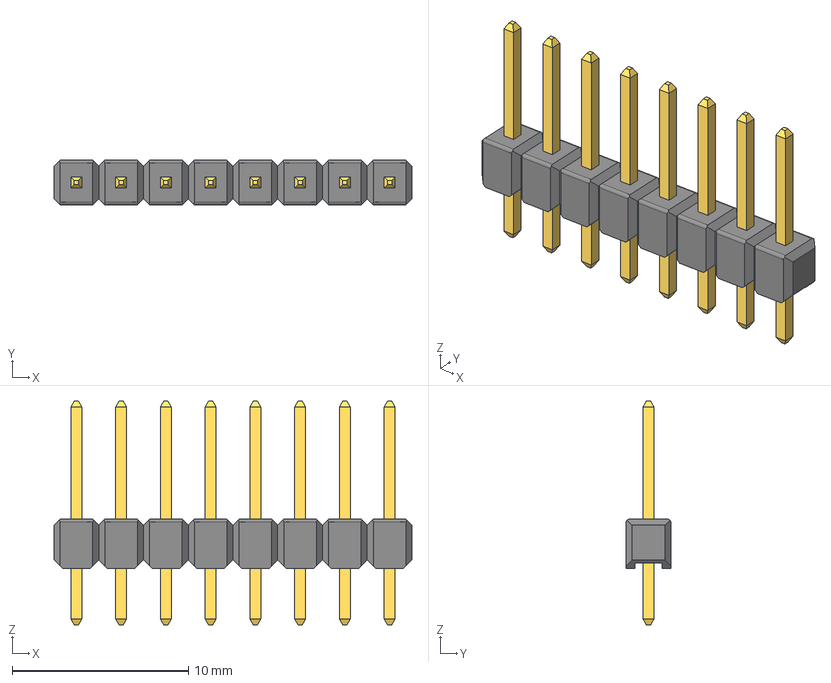
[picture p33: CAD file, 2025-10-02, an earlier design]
old_repos/Elec2019-20/Cartes/Custom/steps/Pin Header 1x8 TH Pitch 2.54mm.stp
20.3 x 2.54 x 12.7 mm

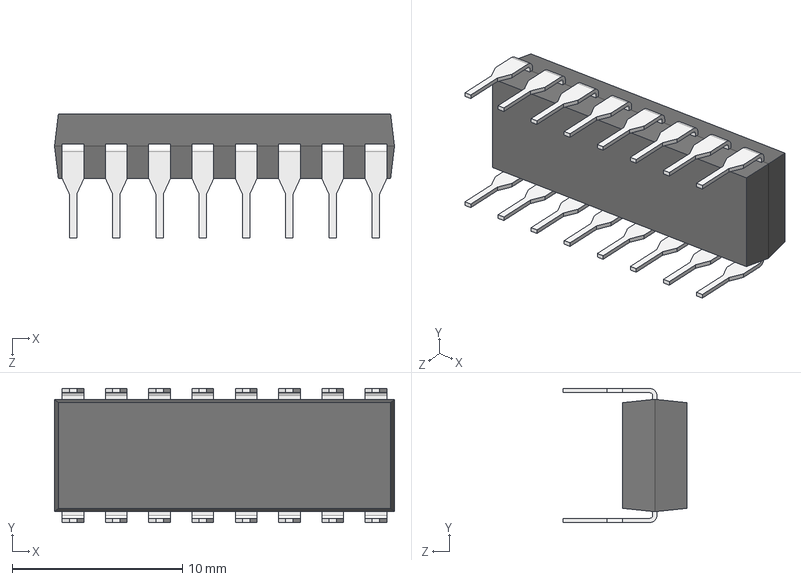
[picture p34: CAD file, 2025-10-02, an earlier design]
old_repos/Elec2019-20/Cartes/Custom/steps/DIP_16pins.stp
20.0 x 7.87 x 7.30 mm

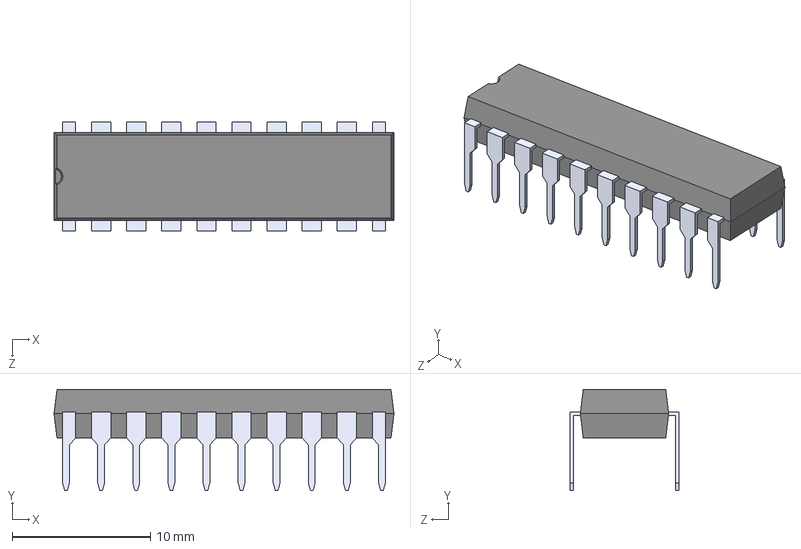
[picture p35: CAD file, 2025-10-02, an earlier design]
old_repos/Elec2019-20/Cartes/Custom/steps/DIP_20pins.stp
24.6 x 7.31 x 7.87 mm
74HC245_TOSHIBA_PIN2 x 16
74HC295_TOSHIBA_BODY
74HC245_TOSHIBA_PIN10 x 2
74HC245_TOSHIBA_PIN1 x 2

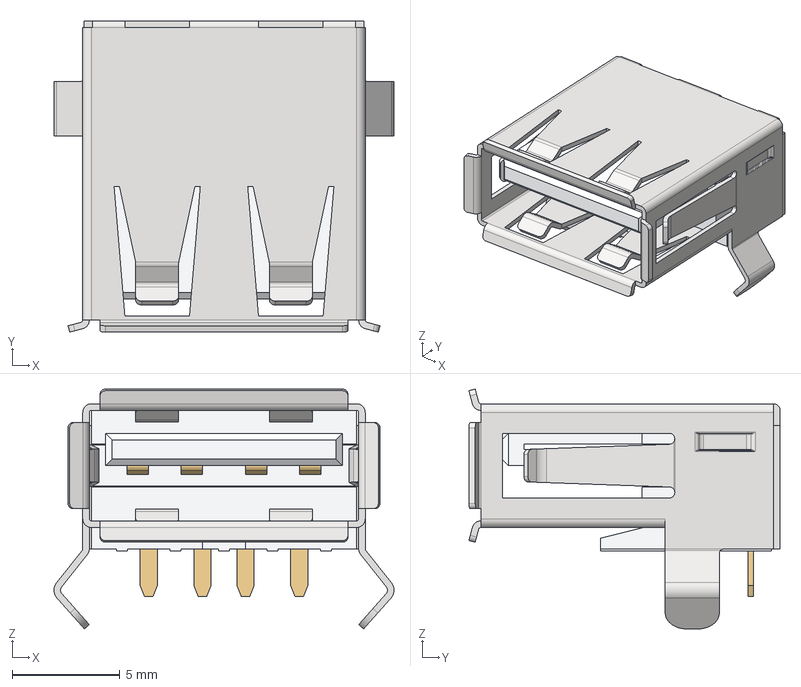
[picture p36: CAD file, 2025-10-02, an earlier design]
old_repos/Elec2019-20/Cartes/Custom/steps/femaleThruHoleUSB.stp
15.8 x 14.4 x 11.1 mm

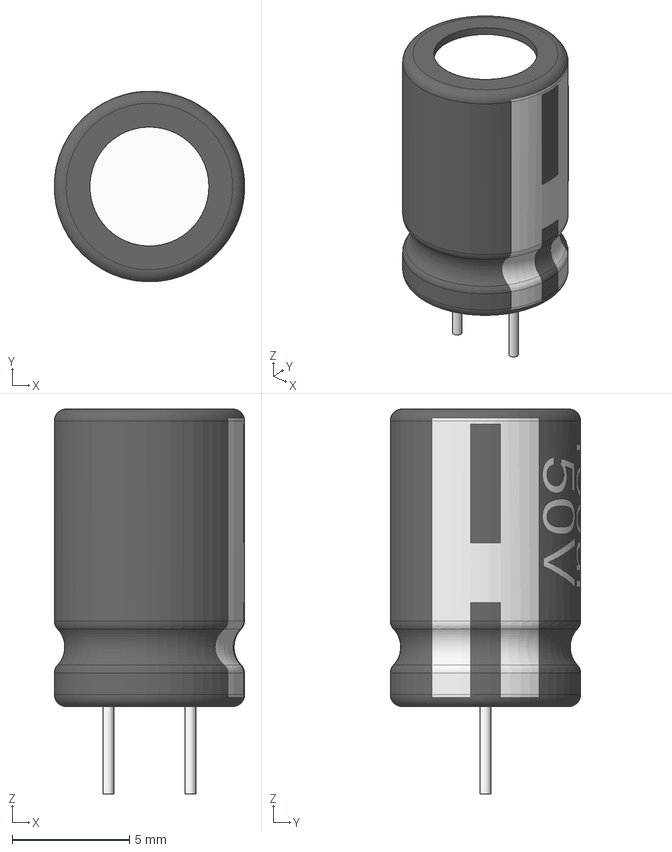
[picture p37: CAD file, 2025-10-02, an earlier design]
old_repos/Elec2019-20/Cartes/Custom/steps/Cond_100uF_50V.stp
8.13 x 8.13 x 16.4 mm

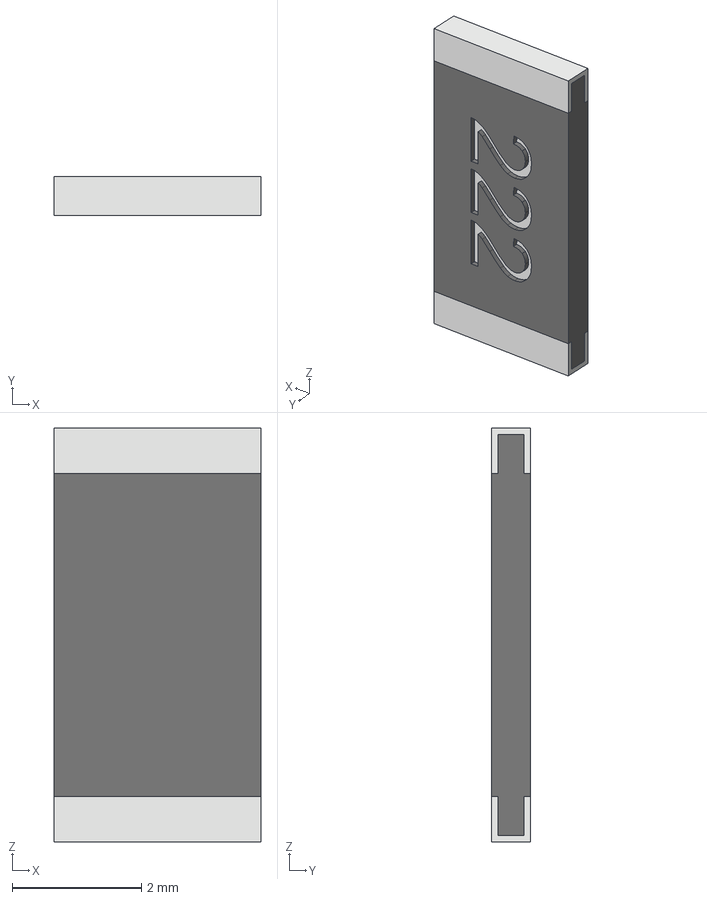
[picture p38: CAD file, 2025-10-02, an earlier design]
old_repos/Elec2019-20/Cartes/Custom/steps/CRA2520.step
3.20 x 0.6 x 6.40 mm

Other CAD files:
old_repos/Elec2019-20/Cartes/Custom/steps/DIP_6pins.step
old_repos/Elec2019-20/Cartes/Custom/steps/DRV8825.stp
old_repos/Elec2019-20/Cartes/Custom/steps/DRV8825_2.STEP
old_repos/Elec2019-20/Cartes/Custom/steps/FuseHolder.stp
old_repos/Elec2019-20/Cartes/Custom/steps/MiniFit_Jr_3x2.stp
old_repos/Elec2019-20/Cartes/Custom/steps/Molex_KK254_2.stp
old_repos/Elec2019-20/Cartes/Custom/steps/Molex_KK254_2H.stp
old_repos/Elec2019-20/Cartes/Custom/steps/Molex_MinifitJr_2D.stp
old_repos/Elec2019-20/Cartes/Custom/steps/Pin Header 1x1 TH 2.54mm Pitch.stp
old_repos/Elec2019-20/Cartes/Custom/steps/SO-14_Narrow.stp
old_repos/Elec2019-20/Cartes/Custom/steps/TO252.STEP
old_repos/Elec2019-20/Cartes/Custom/steps/Traco_1x1inch.stp
old_repos/Elec2019-20/Cartes/Custom/steps/Traco_tsr.stp
old_repos/Elec2019-20/Cartes/Custom/steps/molex_22_12_4032.stp
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

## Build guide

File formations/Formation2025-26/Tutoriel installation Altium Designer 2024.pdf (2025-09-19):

## Tutoriel installation Altium Designer 2024 (Octobre 2024) / Altium Designer 2024 installation tutorial (October 2024)

Développé par la société australienne Altium Limited, Altium Designer est un logiciel de conception assistée par ordinateur (CAO) pour l’électronique et les circuits imprimés (PCB) très utilisé dans l’industrie tout autour du globe. Depuis octobre 2024, l’ISAE Supaero permet à ses étudiants d’obtenir gratuitement des licences étudiantes renouvelables chaque année jusqu’à obtention du diplôme. / Developed by Australian company Altium Limited, Altium Designer is a computer-aided design (CAD) software package for electronics and printed circuit boards (PCBs) widely used in industry around the globe. Since October 2024, ISAE Supaero has allowed its students to obtain free student licences, renewable every year until they graduate.

Voici les recommandations systèmes (https://www.altium.com/documentation/altium-designer/system-requirements) pour faire tourner le logiciel. Il n’est pas très gourmant en ressources et peut facilement tourner sur la majorité des ordinateurs. Attention, il n’est disponible que sur Windows. / Here are the system recommendations (https://www.altium.com/documentation/altium-designer/system-requirements) for running the software. It is not very resource-intensive and can easily run on most computers. Please note that it is only available for Windows.

Allez sur le site du Student Lab d'Altium en suivant ce lien. (https://www.altium.com/fr/education/students/) / Go to the Altium Student Lab website by following this link. (https://www.altium.com/fr/education/students/)

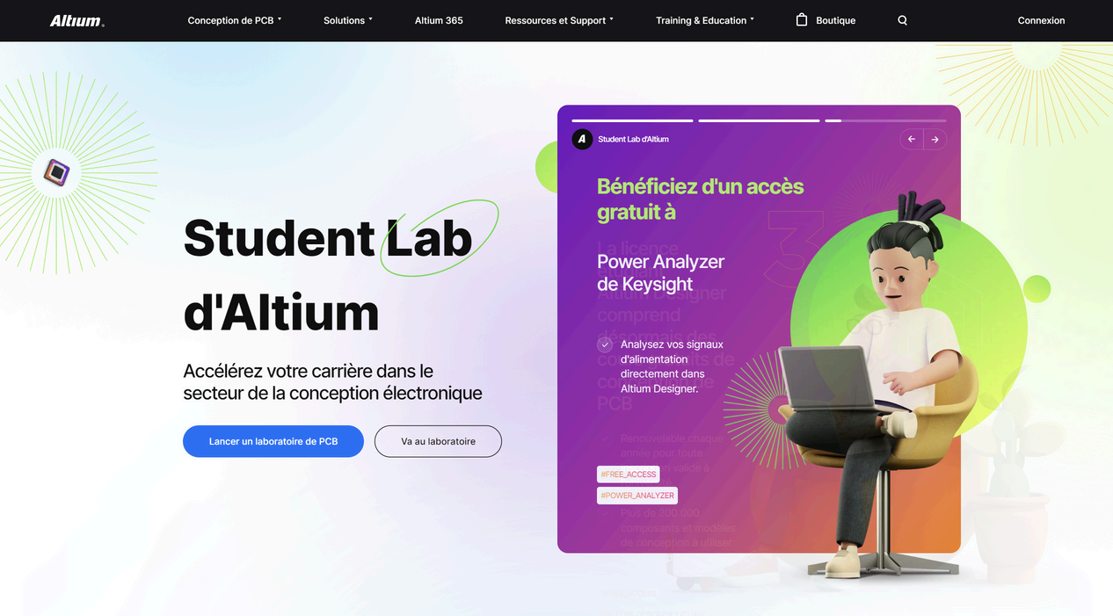
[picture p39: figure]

Appuyez sur Lancer un laboratoire PCB, puis entre votre adresse email Supaero et ISAE SUPAERO dans le nom de l’université. Une nouvelle page s’ouvre. / Click on Enroll for free, then enter your Supaero email address and ISAE SUPAERO in the university name. A new page will open.

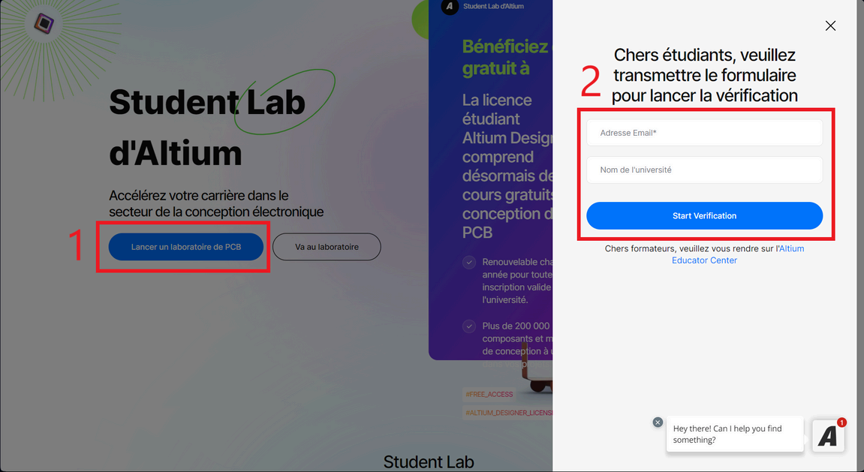
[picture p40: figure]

Appuyez sur Démarrer. / Press Start.

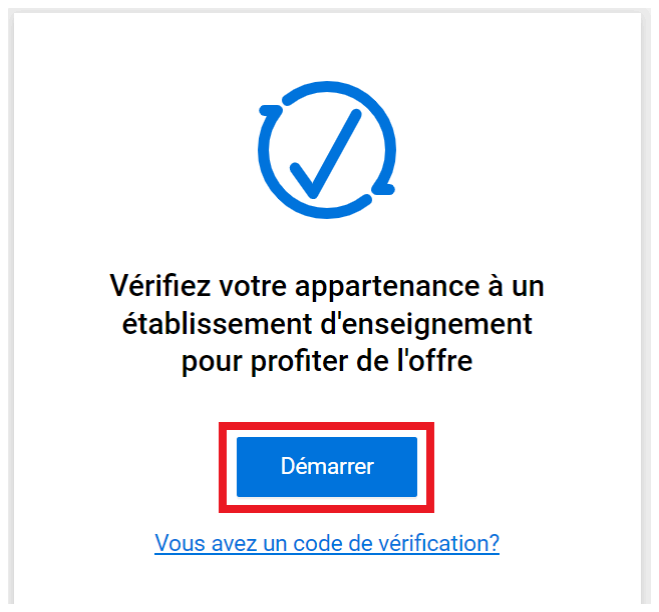
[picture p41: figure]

L'institut est bel et bien enregistré dans la base de donnée d'Altium, mais il n'apparaît pas dans la liste des écoles pour le moment. Appuyez donc sur Vous ne trouvez pas votre établissement ?. / The institute is indeed registered in the Altium database, but it does not appear in the list of schools at the moment. Click on Can't find your school ?

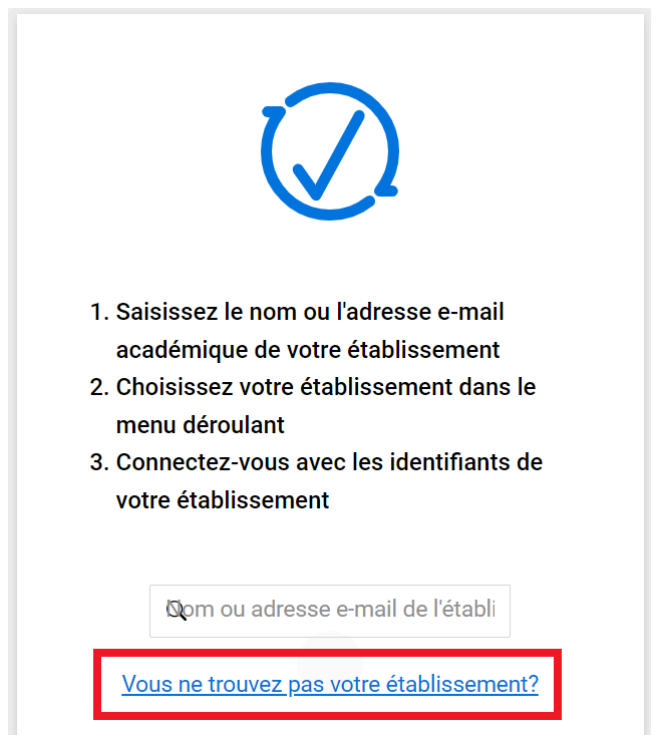
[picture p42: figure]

Entrez votre adresse email Supaero puis appuyez sur Soumettre. / Enter your Supaero email address then press Submit.

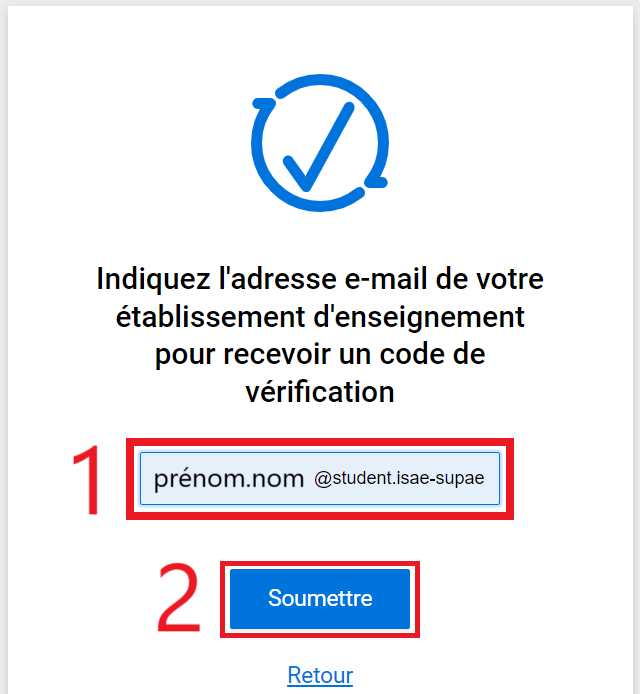
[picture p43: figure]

Vous recevrez par mail un code et un lien. Copiez le code et allez sur le lien, qui vous ramènera sur une page déjà visitée. Cette fois, appuyez sur Vous avez un code de vérification ? / You will receive a code and a link by email. Copy the code and go to the link, which will take you back to a page you've already visited. This time, click on Do you have a verification code?

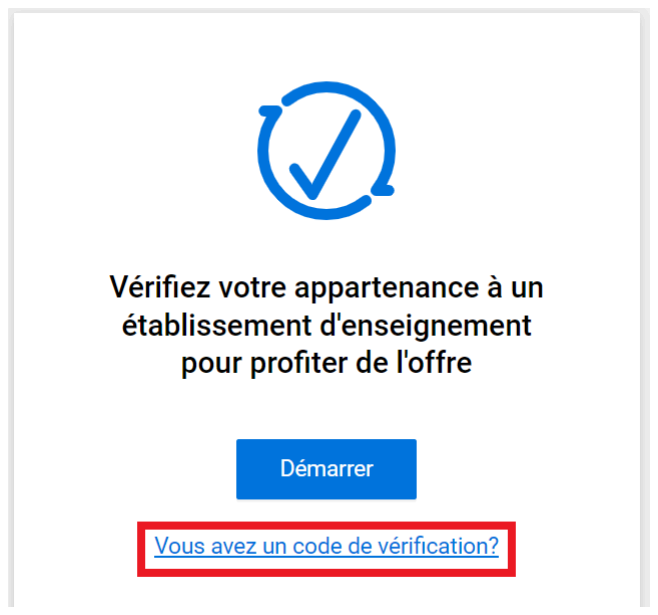
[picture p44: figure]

Entrez encore une fois votre adresse email Supaero et le code obtenu par mail, puis appuyez sur Soumettre. Une nouvelle page s'ouvre. / Once again, enter your Supaero email address and the code you received by email, then press Submit. A new page will open.

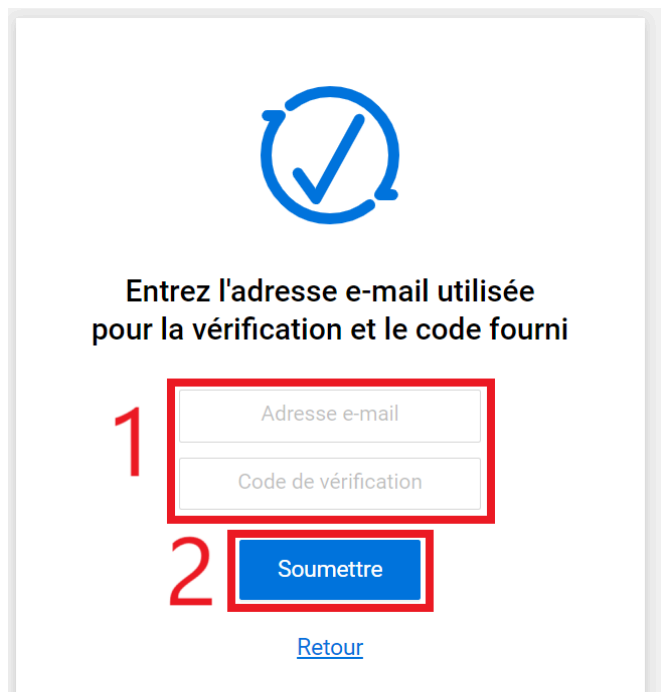
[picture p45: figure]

Remplissez vos informations, puis appuyez sur Obtenir ma version d'essai gratuite. Précision : ce que vous obtiendrez au final n’est pas une version d’essai gratuite comme mentionné, mais bel et bien une licence étudiante. / Fill in your details, then press Get my free trial version. Please note: what you end up with is not a free trial version as mentioned, but a student licence.

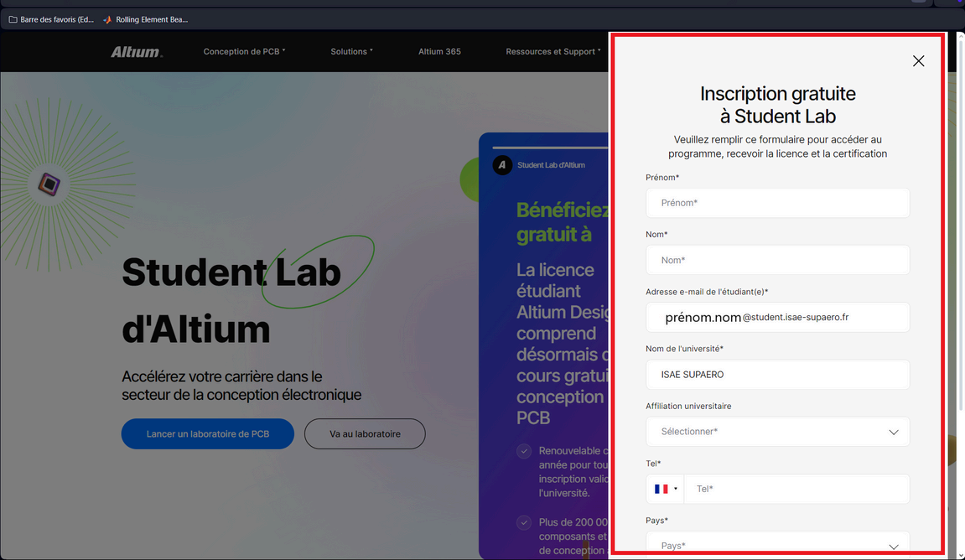
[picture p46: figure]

Vous recevrez plusieurs mails pour confirmer votre compte et installer le logiciel. Le téléchargement peut se faire via ce site (https://www.altium.com/fr/products/downloads/) en appuyant sur le bouton "Download (exe, XX MB)
Vous recevrez trois mails. Commencez par vérifier votre licence étudiante en suivant le lien du mail correspondant. / You will receive three emails. Start by checking your student licence by following the link in the corresponding e-mail.

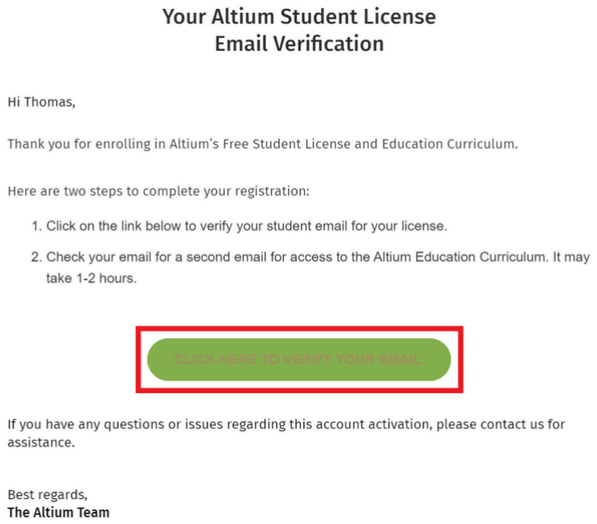
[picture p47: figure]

Les deux autres mails vous donnent les informations des deux licences fournies par la version étudiante : une licence Altium Designer Professional pour accéder au logiciel et une licence Power Analyzer by Keysight qui vous donne accès a une extension du logiciel. Suivez les instructions du mail Student License Information for Altium Designer en appuyant sur Activate AltiumLive. / The other two emails give you information about the two licences supplied with the student version: an Altium Designer Professional licence to access the software and a Power Analyzer by Keysight licence which gives you access to an extension of the software. Follow the instructions in the Student License Information for Altium Designer email by clicking on Activate AltiumLive.

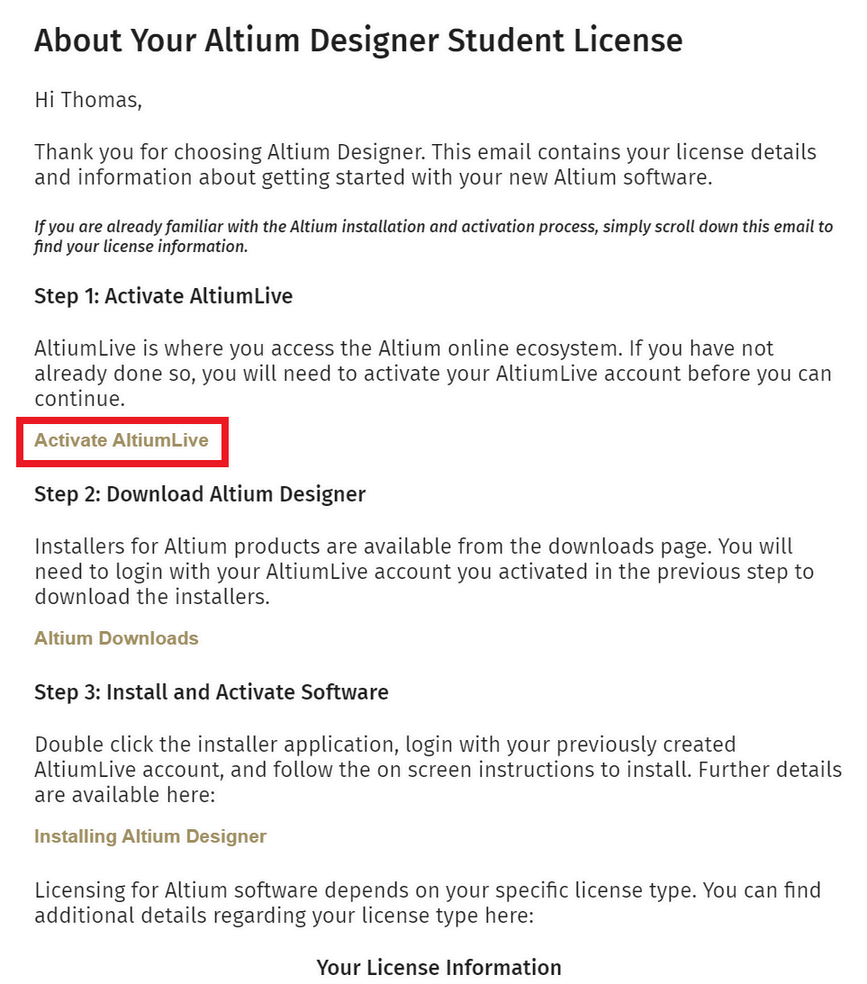
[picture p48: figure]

Une fois AltiumLive activé, vous devriez être redirigé vers le site de téléchargement. Si ce n’est pas le cas, vous pouvez y accéder avec ce lien (https://www.altium.com/fr/products/downloads/) ou en appuyant sur Altium Downloads dans le mail Student License Information for Altium Designer. / Once AltiumLive has been activated, you should be redirected to the download site. If not, you can access it via this link (https://www.altium.com/fr/products/downloads/) or by clicking on Altium Downloads in the Student License Information for Altium Designer email .

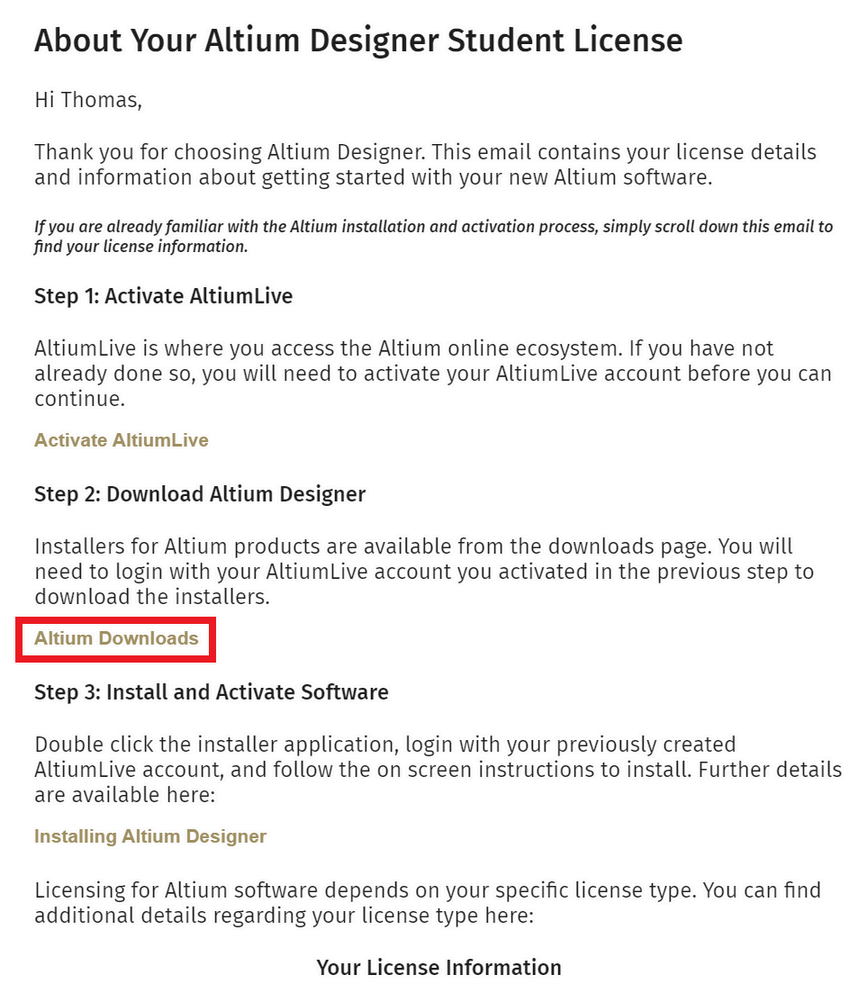
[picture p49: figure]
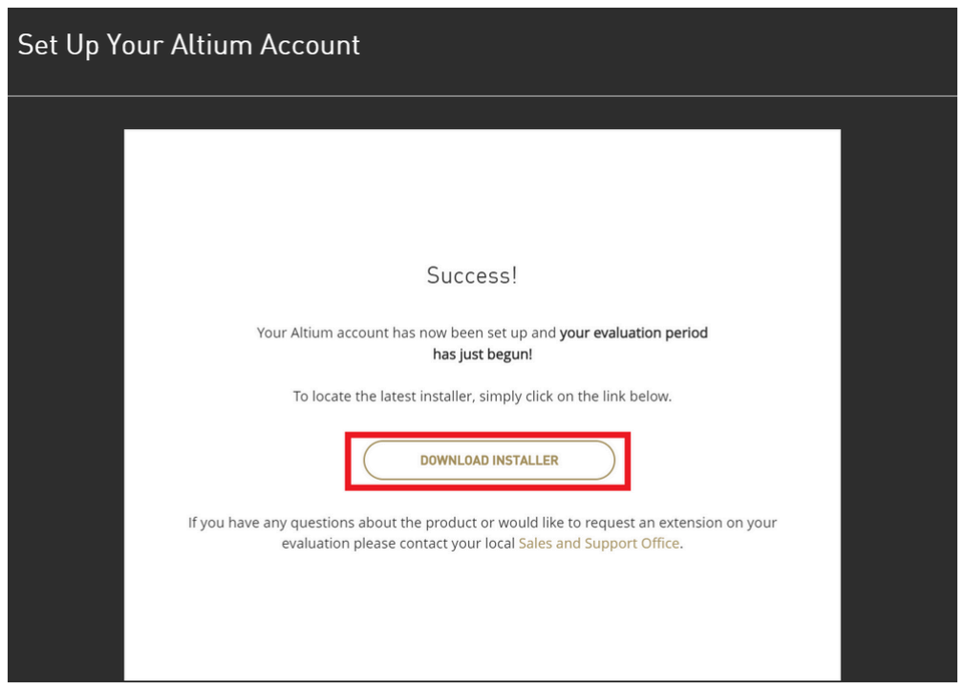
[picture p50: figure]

Vous pouvez télécharger l’installeur avec le bouton Download (exe, XX MB) sur la droite. Exécutez le pour lancer l’installation du logiciel. L’installation est plutôt rapide. / You can download the installer using the Download button (exe, XX MB) on the right. Run it to start installing the software. Installation is fairly quick.

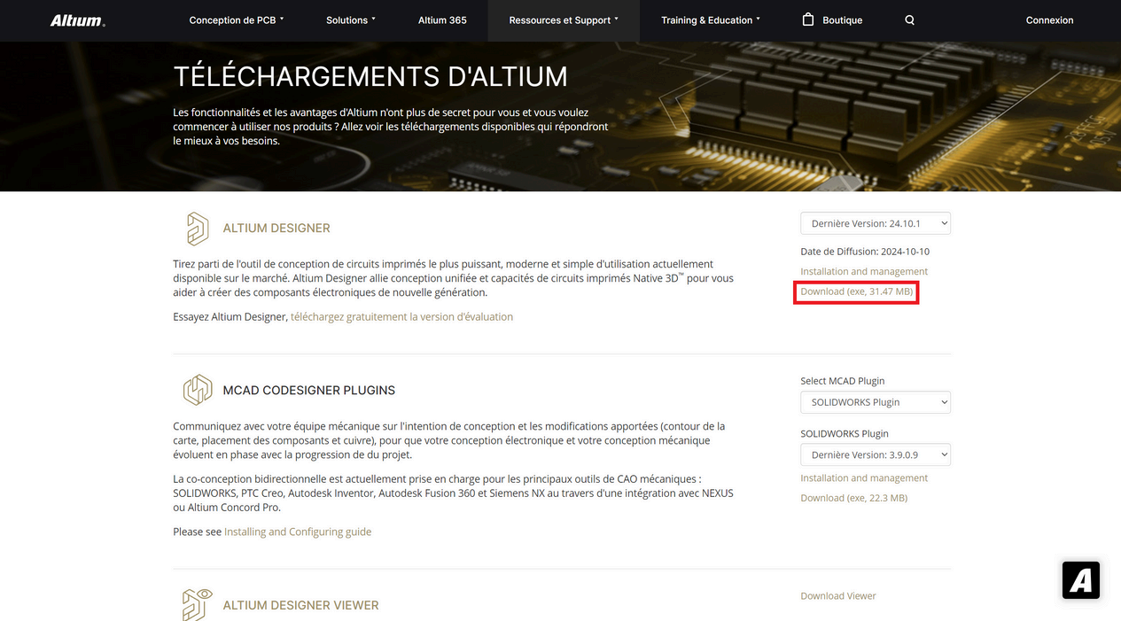
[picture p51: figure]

Une fois l'installation terminée, vous pourrez vous connecter avec votre compte et lancer Atlium. La première page qui s'ouvre alors vous permet d'utiliser votre licence sur votre ordinateur en appuyant sur Utiliser la licence. / Once the installation is complete, you can log in with your account and launch Atlium. The first page that opens allows you to use your licence on your computer by clicking on Use licence.

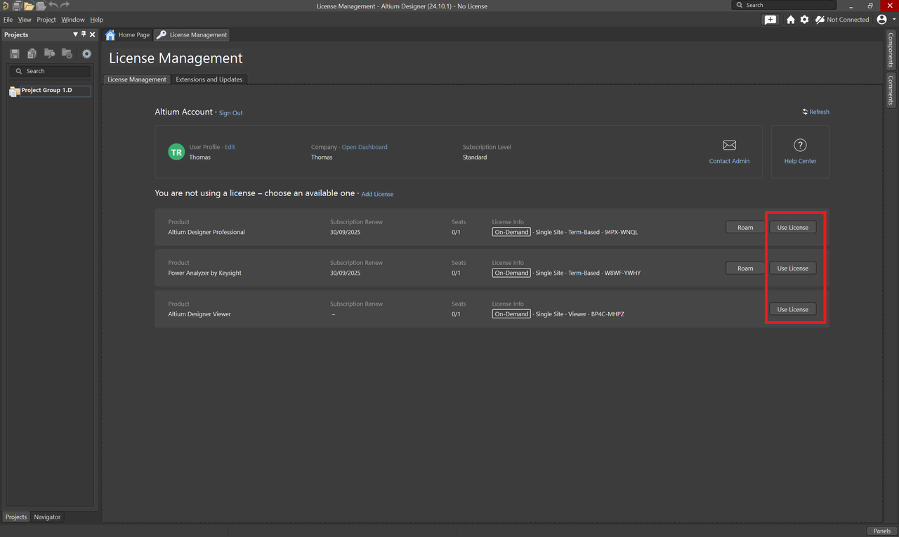
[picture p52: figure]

Profitez de votre licence ! / Enjoy your licence !
Il est possible de télécharger des extensions supplémentaires (comme Power Analyzer by Keysight fourni avec la licence étudiante, ou une extension de compatibilité avec KiCad) à partir de l’onglet Extensions and Updates. / Additional extensions (such as Power Analyzer by Keysight supplied with the student licence, or a KiCad compatibility extension) can be downloaded from the Extensions and Updates tab.

Si vous souhaitez prendre en main le logiciel en autonomie, ou en apprendre plus sur les PCB en général et leur conception, beaucoup de ressources sont accessibles gratuitement. Vous pouvez les retrouver sur la Page d’accueil > Centre de formation ou aux liens suivants. De nombreux tutoriels sont aussi disponibles sur internet. / If you'd like to get to grips with the software on your own, or learn more about PCBs in general and their design, there are a number of resources available free of charge. You can find them on the Home Page > Training Centre or at the following links. Many tutorials are also available on the internet.

Ressources diverses (articles) / Miscellaneous resources (articles) (https://resources.altium.com/fr) Cours (en bas de la page) / Courses (bottom of page) (https://education.altium.com/)
Plus de cours ! / More courses ! (https://my.altium.com/altium-designer/training)

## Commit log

2025-09-19 Repo2025-26 coucouu
    [1_Demo_Footprint.PrjPcb, 1_Demo_Footprint.SchDoc, 1_Footprint.PcbDoc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]
2025-09-24 teensy 4.0 footprint
    [Carte_Propu.PrjPCB, PCB_Propu.PcbDoc, Sch_Propu.SchDoc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]
2025-09-24 ajout libraries teensy
2025-09-24 ajout libraries teensy (auto)
2025-09-24 cartes utiles
    [GR_Alim.PcbDoc, GR_Alim.PrjPCB, GR_Alim.SchDoc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]
2025-09-27 schéma 2ème batterie test
    [GR_Alim.SchDoc]
2025-10-02 modif carte BR
    [GR_Action_Ascensseur.SchDoc, GR_Alim.PcbDoc, GR_Alim.PrjPCB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]
2025-10-26 Cartes propu, alim, action v1
    [Carte_Propu.PrjPCB, Carte_Propu2026.PrjPCB, GR_Alim.PcbDoc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]
2025-10-27 petit oubli
    [GR_Alim.SchDoc, Sch_Propu.SchDoc, carteAction2026.SchDoc]
2025-10-28 Réellement soudé Alim 2021
    [GR_Alim.SchDoc]
2025-10-31 J'ai enlevé un max d'erreurs au lancement d'Altium, mais il reste des soucis de librairies pour la carte de propu
    [Carte_Propu2026.PrjPCB, GR_Alim2026.PrjPCB, Raspi_Hat.PrjPcb]
2025-11-04 Modif (merci Oriane)
    [CarteAction_PontLevis2026.SchDoc, Carte_Propu2026.PrjPCB, GR_Alim.SchDoc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]
2025-11-04 Dégage 2è batterie
    [CarteAction_PontLevis2026.SchDoc, GR_Alim.SchDoc, Split_photodiodes_Pumps2026.SchDoc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]
2025-11-04 Modif jsp pleins de choses
    [CarteAction_PontLevis2026.SchDoc, GR_Alim.SchDoc, Sch_Propu.SchDoc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]
2025-11-19 Cartes propu & alim V1
    [CarteAction_PontLevis2026.SchDoc, Carte_Propu2026.PrjPCB, GR_Alim.SchDoc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]
2025-11-21 carte action pcb v1
    [CarteAction_PontLevis2026.SchDoc, Carte_Propu2026.PrjPCB, GR_Alim2026.PrjPCB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]
2025-11-21 cartes gr v2 (vf ?)
    [CarteAction_PontLevis2026.SchDoc, Carte_Propu2026.PrjPCB, GR_Alim2026.PcbDoc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]
2025-11-22 carte action v3
    [1_Demo_Footprint.PrjPcb, 1_Demo_Footprint.SchDoc, 1_Footprint.PcbDoc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]
2025-11-22 vf (ou pas)
    [CarteAction_PontLevis2026.SchDoc, GR_Alim2026.PcbDoc, PCB_Propu2026.PcbDoc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]
2025-11-22 ajout split bumpers carte propu
    [GR_Alim2026.PcbDoc, PCB_Propu2026.PcbDoc, Split_action2026.PcbDoc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]
2025-11-25 Update Split_action2026.PcbDoc
    split action
    [Split_action2026.PcbDoc]
2025-12-01 modif carte pompe
    [Split_action2026.PcbDoc, Split_action2026.PrjPcb]
2025-12-02 footprint connecteur 6 droit
    [Split_action2026.PcbDoc, Split_action2026.PrjPcb, Split_action2026.SchDoc]
2025-12-03 modif carte action
    [Split_action2026.PcbDoc]
2025-12-16 cartes pami
    [SchemaGroupie.SchDoc, carte_ecureuil2026.PrjPcb, carte_ecureuil2026.SchDoc]
2026-01-05 worked on the card for the ecureuil robot
    [carte_ecureuil2026.SchDoc]
2026-01-06 worked on the card of the ecureuil - almost finished - still some connections to do
    [carte_ecureuil2026.SchDoc]
2026-01-20 commencé à relier les éléments du schéma de la carte, et delimité les éléments
    [carte_ecureuil2026.SchDoc]
2026-01-20 carte split action antoine 2A
    [PCB_Propu2026.PcbDoc, Split_action2026.PcbDoc, Split_action2026.SchDoc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]
2026-01-21 quelques ajouts
    [carte_ecureuil2026.SchDoc]
2026-01-21 carte action
    [Split_action2026.PcbDoc]
2026-01-21 carte action blabla
    [Split_action2026.PcbDoc]
2026-01-21 carte action mini modif
    [Split_action2026.PcbDoc]
2026-01-21 carte split action fini
    [Split_action2026.PcbDoc, Split_action2026.PrjPcb]
2026-01-21 gerber files commande 2
    [Carte_Propu2026.PrjPCB, GR_Alim2026.PrjPCB, Split_Pumps.SchDoc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]
2026-01-27 modèle 3D pour le gros téo
    [GR_Alim2026.step, PCB_Propu2026.step, carteAction2026v4.step]
2026-02-03 carte bien avancée
    [carte_ecureuil2026.PcbDoc, carte_ecureuil2026.SchDoc]
2026-02-17 ca avance
    [carte_ecureuil2026.PcbDoc, carte_ecureuil2026.SchDoc]
2026-03-03 presque fini
    [Split_propu2026.PcbDoc, carte_ecureuil2026.PcbDoc, carte_ecureuil2026.SchDoc]
2026-03-10 almost finished ecureuil
    [carte_ecureuil2026.PcbDoc]
2026-03-10 carte ecureuil v0 terminée
    [carte_ecureuil2026.PcbDoc]
2026-03-10 carte ecurieul quasi finie
    [carte_ecureuil2026.PcbDoc]
2026-03-16 modif final carte ecureuil & ninja
    [carte_ecureuil2026.PcbDoc, carte_ecureuil2026.PrjPcb, carte_ecureuil2026.SchDoc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]
2026-03-16 carte ninja finie, manque fusible sur pami
    [carte_ecureuil2026.PcbDoc, carte_ecureuil2026.SchDoc, carte_ninja2026.PcbDoc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]
2026-03-16 ecureuil v1 avec fusible bof fini
    [carte_ecureuil2026.PcbDoc, carte_ecureuil2026.PrjPcb, carte_ecureuil2026.SchDoc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]
2026-03-17 fichier gerber pami
    [carte_ecureuil2026.PcbDoc, carte_ecureuil2026.PrjPcb, carte_ecureuil2026v2.PcbDoc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]
2026-05-15 commentaire pin boot
    [carte_ecureuil2026.SchDoc]
2026-05-19 adding esp32 pinout to readme
2026-11-10 omg ecran implémenté team elec de fou nul les autres go Minecraft
2026-11-10 Une autre carte mais c'est la meme tkt
